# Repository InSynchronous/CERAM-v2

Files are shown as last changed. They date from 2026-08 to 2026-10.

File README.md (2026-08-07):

# CERAM

Cost Effective Rocket Aviation Module.

CERAM is a flight computer board for model rocketry, built around a simple idea: instead of hand soldering a big board full of tiny SMD parts, you plug in cheap breakout boards that cost a couple of dollars each. The board just wires them together.

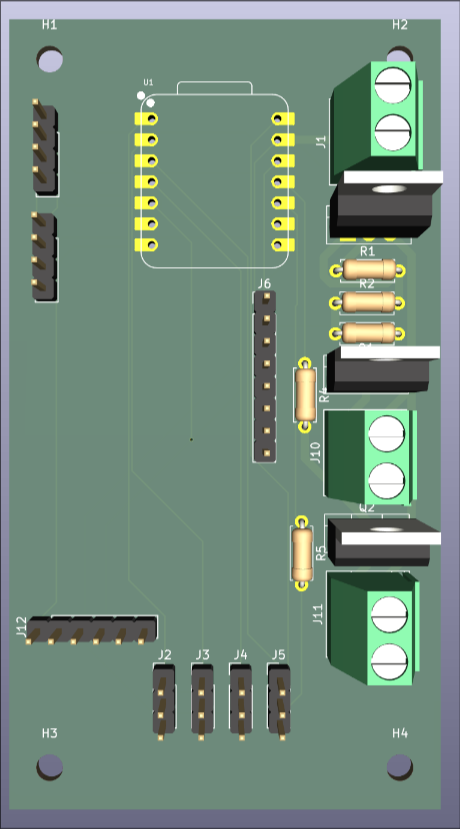
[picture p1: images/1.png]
CERAM board top view


## Why

Making a rocket flight computer usually means picking one of two paths. Either you buy a commercial unit and spend a lot of money, or you design your own PCB with a bare microcontroller, an IMU, a barometer and a pile of passives, then try to hand solder QFN packages with a normal iron. The second option likely results in failure.

## What is on it

CERAM is a carrier board. What goes on top of it defines its actual use.

- A Seeed Studio Xiao ESP32-S3 board serving as the MCU of the entire stack
- An MPU-6050 or other compatible IMU
- A BMP280 or other compatible barometer
- 4 PWM outputs
- A UART Header
- An I2C Header
- A LM317 for voltage regulation
- Two IRLZ44N MOSFETs for parachute deployment/reaction wheel driving/motor igniting/pyrotechnic uses

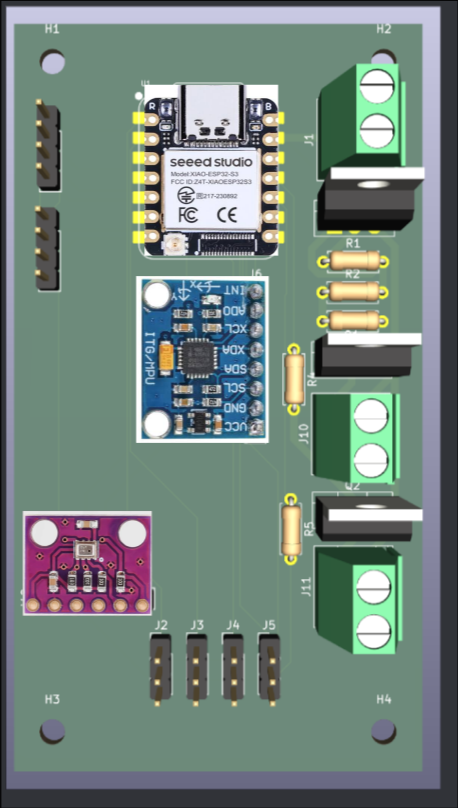
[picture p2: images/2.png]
Board with everything labeled


## BOM

| Part | Link | Cost |
|---|---|---|
| Screw Terminals 5.08mm | <https://www.aliexpress.us/item/2251832621219818.html> | $1.96 |
| Resistor Kit (not requesting) (1x 220ohm 2x 330ohm 3x 10k ohm) | <https://www.aliexpress.us/item/3256808562766775.html> | $3.17 |
| IRLZ44N (not requesting)| <https://www.aliexpress.us/item/3256807934257560.html> | $2.30 |
| LM317 | <https://www.aliexpress.us/item/3256803468041967.html> | $1.91 |
| Header Pins | <https://www.aliexpress.us/item/3256807247428541.html> | $1.84 |
| Seeed Studio Xiao ESP32-S3 (equal to or less than aliexpress pricing when including shipping charges) | <https://www.amazon.com/ESP32S3-2-4GHz-Dual-core-Supported-Efficiency-Interface/dp/B0BYSB66S5> | $16.99 |
| BMP280 (aliexpress only has fake clones trust me) | <https://www.amazon.com/Atmospheric-Pressure-Modules-Barometric-Compatible/dp/B0FDWN2LVS/> | $6.62 |
| MPU6050 | <https://www.aliexpress.us/item/3256809482368154.html> | $2.82 |
| JLC PCB | (see CERAM-V2.zip in pcb/production) | $5.30 |
| Total | . | $42.91 |

## Software
Included is a board test program (`firmware/BoardTest`) that initializes the IMU, barometer, and servos and streams all sensor readings over serial.
Please use the build.sh command to build and flash (you may need to change ports).

## PCB
Completed gerbers can be found in `pcb/production/CERAM-V2.zip` and `gerbers.zip`.

### Schematic
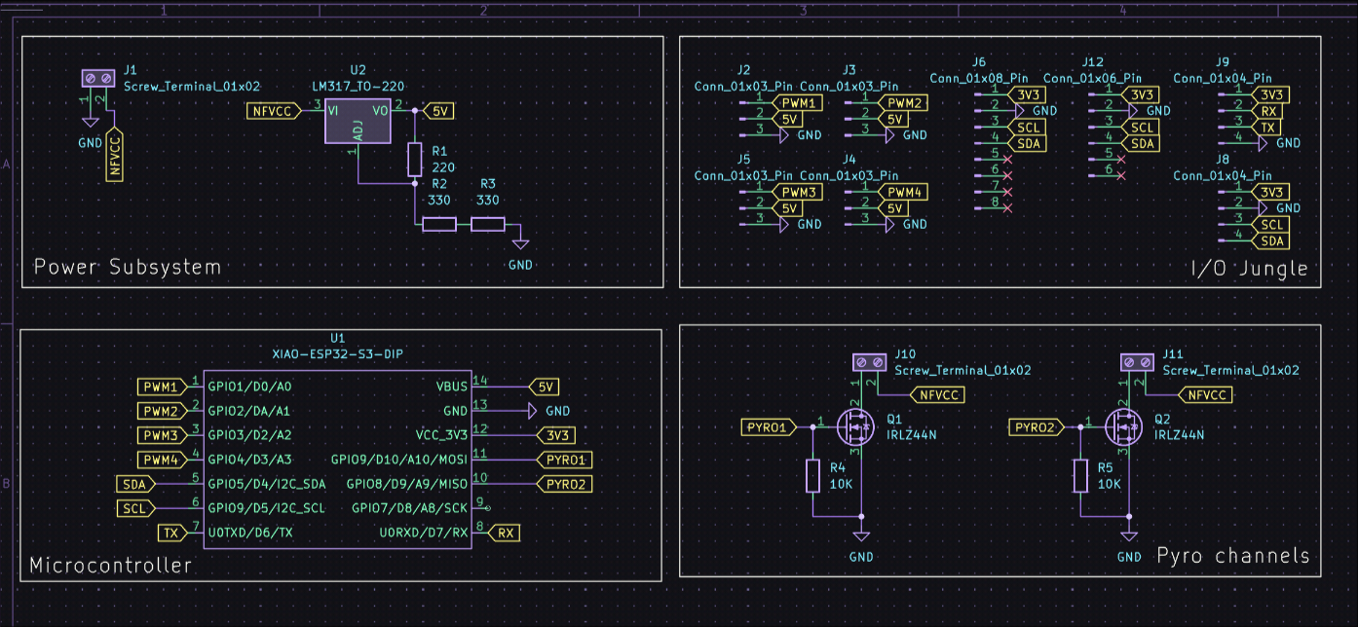
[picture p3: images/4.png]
Schematic


### PCB
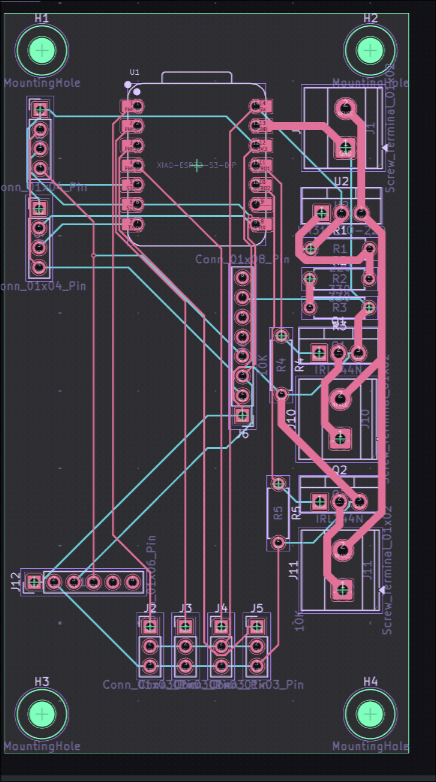
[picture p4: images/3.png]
PCB


## License

MIT. See LICENSE.

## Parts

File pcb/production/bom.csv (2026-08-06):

Designator | Footprint | Quantity | Value | LCSC Part #
J1, J10, J11 | TerminalBlock_Phoenix_MKDS-1,5-2-5.08_1x02_P5.08mm_Horizontal | 3 | Screw_Terminal_01x02
J12 | PinHeader_1x06_P2.54mm_Vertical | 1 | Conn_01x06_Pin
J2, J3, J4, J5 | PinHeader_1x03_P2.54mm_Vertical | 4 | Conn_01x03_Pin
J6 | PinHeader_1x08_P2.54mm_Vertical | 1 | Conn_01x08_Pin
J8, J9 | PinHeader_1x04_P2.54mm_Vertical | 2 | Conn_01x04_Pin
Q1, Q2 | TO-220-3_Vertical | 2 | IRLZ44N
R1 | R_Axial_DIN0207_L6.3mm_D2.5mm_P7.62mm_Horizontal | 1 | 220
R2, R3 | R_Axial_DIN0207_L6.3mm_D2.5mm_P7.62mm_Horizontal | 2 | 330
R4, R5 | R_Axial_DIN0207_L6.3mm_D2.5mm_P7.62mm_Horizontal | 2 | 10K
U1 | XIAO-ESP32S3-DIP | 1 | XIAO-ESP32-S3-DIP
U2 | TO-220-3_Vertical | 1 | LM317_TO-220

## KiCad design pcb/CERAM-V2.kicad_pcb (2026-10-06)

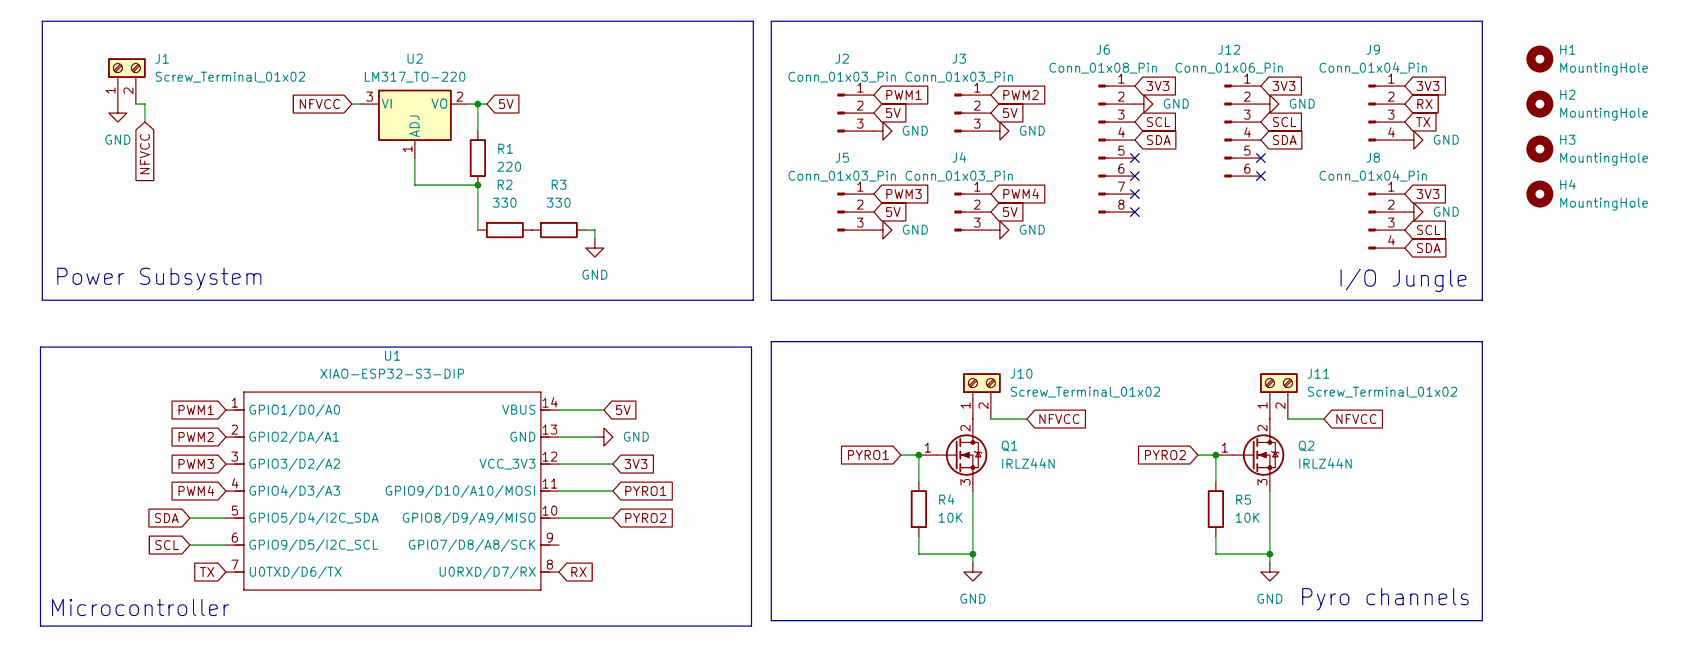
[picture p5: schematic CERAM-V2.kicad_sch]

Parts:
H1, H2, H3, H4: MountingHole; MountingHole_3.2mm_M3
J1, J10, J11: Screw_Terminal_01x02; TerminalBlock_Phoenix_MKDS-1,5-2-5.08_1x02_P5.08mm_Horizont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
J2, J3, J4, J5: Conn_01x03_Pin; PinHeader_1x03_P2.54mm_Vertical
J6: Conn_01x08_Pin; PinHeader_1x08_P2.54mm_Vertical
J8, J9: Conn_01x04_Pin; PinHeader_1x04_P2.54mm_Vertical
J12: Conn_01x06_Pin; PinHeader_1x06_P2.54mm_Vertical
Q1, Q2: IRLZ44N; TO-220-3_Vertical
R1: 220; R_Axial_DIN0207_L6.3mm_D2.5mm_P7.62mm_Horizontal
R2, R3: 330; R_Axial_DIN0207_L6.3mm_D2.5mm_P7.62mm_Horizontal
R4, R5: 10K; R_Axial_DIN0207_L6.3mm_D2.5mm_P7.62mm_Horizontal
U1: XIAO-ESP32-S3-DIP; XIAO-ESP32S3-DIP
U2: LM317_TO-220; TO-220-3_Vertical

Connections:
3V3: J6.1, J8.1, J9.1, J12.1, U1.12 (VCC_3V3)
5V: J2.2, J3.2, J4.2, J5.2, R1.1, U1.14 (VBUS), U2.2 (VO)
GND: J1.1, J2.3, J3.3, J4.3, J5.3, J6.2, J8.2, J9.4, J12.2, Q1.3 (S), Q2.3 (S), R3.1, R4.2, R5.2, U1.13 (GND)
NFVCC: J1.2, J10.2, J11.2, U2.3 (VI)
unnamed: J10.1, Q1.2 (D)
unnamed: J11.1, Q2.2 (D)
unnamed: R2.1, R3.2
unnamed: R1.2, R2.2, U2.1 (ADJ)
PWM1: J2.1, U1.1 (GPIO1/D0/A0)
PWM2: J3.1, U1.2 (GPIO2/DA/A1)
PWM3: J5.1, U1.3 (GPIO3/D2/A2)
PWM4: J4.1, U1.4 (GPIO4/D3/A3)
PYRO1: Q1.1 (G), R4.1, U1.11 (GPIO9/D10/A10/MOSI)
PYRO2: Q2.1 (G), R5.1, U1.10 (GPIO8/D9/A9/MISO)
RX: J9.2, U1.8 (U0RXD/D7/RX)
SCL: J6.3, J8.3, J12.3, U1.6 (GPIO9/D5/I2C_SCL)
SDA: J6.4, J8.4, J12.4, U1.5 (GPIO5/D4/I2C_SDA)
TX: J9.3, U1.7 (U0TXD/D6/TX)

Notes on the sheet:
I/O Jungle
Microcontroller
Pyro channels
Power Subsystem

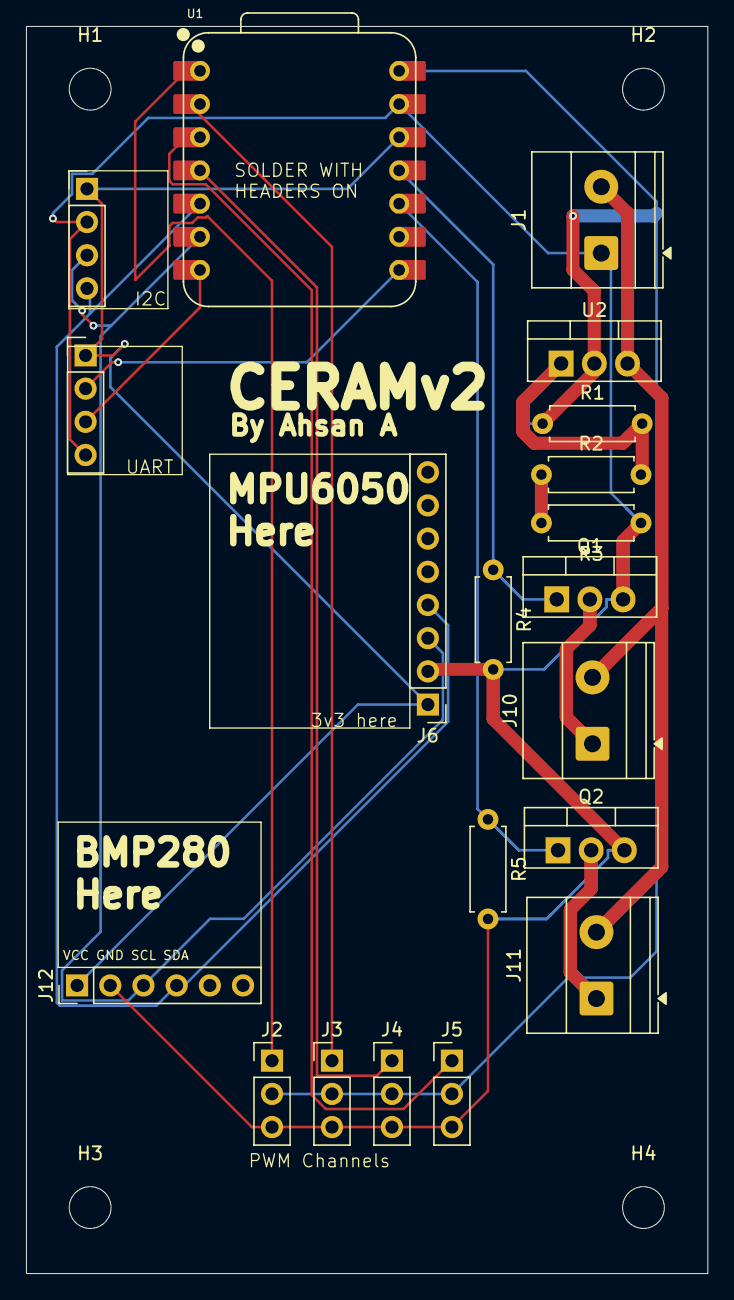
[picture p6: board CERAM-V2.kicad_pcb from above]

Board: 2 copper layers, 52.2 x 95.5 mm, 24 parts (0 on the bottom side), 18 nets.

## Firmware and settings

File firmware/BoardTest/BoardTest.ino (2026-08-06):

#include <Wire.h>
#include "MPU6050.h"
#include "StateEstimator.h"
#include "SG90.h"
#include "BMP180.h"
#include "PID.h"
#include "esp32-hal-gpio.h"

MPU6050 imu;
BMP180 baro;

SG90 xservo;
SG90 yservo;

PID xPID(0.4, 0, 0.2);
PID yPID(0.4, 0, 0.2);

MPU6050Data i;
BMP180Data b;

StateEstimator state;

uint32_t lastTime = 0;
uint32_t lastLed = 0;
bool ledState = false;

const uint32_t PERIOD_US = 10000;

void setup() {
	Serial.begin(115200);
	Wire.begin(6, 7);

	imu.init(0x68);
	baro.init(0x77);

	delay(100);
	imu.calibrate(500, 10); // 500 samples @ 10ms
	Serial.printf("IMU drift: {gx=%f, gy=%f, gz=%f}\n", imu.drift.gx, imu.drift.gy, imu.drift.gz);

	xservo.initServo(9); // INNER
	yservo.initServo(2); // OUTER
	pinMode(4, OUTPUT);

	lastTime = micros();
}

void loop() {
	uint32_t now = micros();
	if (now - lastTime >= PERIOD_US) {
		float actual_ms = (now - lastTime) / 1000.0f;
		lastTime += PERIOD_US;

		// IMU: accelerometer + gyro + temperature
		i = imu.getData();

		// Barometer: temperature + pressure + altitude
		b = baro.getData();

		// Fuse gyro rates + baro altitude into an attitude estimate
		state.updateState({i.gx, i.gy, i.gz}, b.altitude, actual_ms);
		Orientation att = state.getOrientation() * RAD_TO_DEG;

		// Level the board: PID tries to drive tilt back to 0
		float xAngle = att.y;
		float yAngle = -att.z; // due to mpu mounting

		int xCommand = (int)xPID.updateLoop(xAngle, 0, 0.01); // state=xAngle, setpoint 0, dt = 10ms
		int yCommand = (int)yPID.updateLoop(yAngle, 0, 0.01); // state=yAngle, setpoint 0, dt = 10ms
		xCommand = constrain(xCommand, -30, 30);
		yCommand = constrain(yCommand, -30, 30);

		xservo.setPosition(90 + xCommand);
		yservo.setPosition(90 + yCommand);

		Serial.printf("t=%lu ms | accel {%f, %f, %f} m/s2 | gyro {%f, %f, %f} deg/s | imu_temp %f C | baro %f C, %f hPa, %f m | att r=%f p=%f y=%f | servo cmd=%d,%d\n",
				now / 1000,
				i.ax, i.ay, i.az,
				i.gx, i.gy, i.gz,
				i.temp,
				b.temperature, b.pressure, b.altitude,
				att.x, att.y, att.z,
				xCommand, yCommand);
	}

	// Heartbeat on pin 4 (LED) every 500ms
	if (now - lastLed >= 500000) {
		lastLed = now;
		ledState = !ledState;
		digitalWrite(4, ledState);
	}
}

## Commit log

2026-08-06 pcb routing
    [CERAM-V2.kicad_pcb, CERAM-V2.kicad_sch]
2026-08-06 Routing fix + readme polish + images + firmware
    [CERAM-V2.kicad_pcb, output.csv]
2026-08-07 rooted gerbers
2026-10-06 silkscreen + moved xiao
    [CERAM-V2.kicad_pcb]
